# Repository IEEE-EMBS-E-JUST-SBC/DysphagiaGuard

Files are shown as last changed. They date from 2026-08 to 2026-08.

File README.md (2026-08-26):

---
publishDate: 2026-08-25T00:00:00Z

title: DysphagiaGuard || IEEE EMBS E-JUST SBC

excerpt: A MYOSA-based TinyML wearable that continuously monitors swallowing kinematics and classifies each swallow as Normal, Delayed/Incomplete, or Aspiration Risk in real time — alerting the wearer locally and notifying caregivers via a companion Flutter app.

image: DysphagiaGuard/cover.jpg

tags:
  - MYOSA
  - TinyML
  - Wearable Health Tech
  - Flutter
  - Embedded Systems
  - Biomedical Engineering
---

> Continuous, at-home swallowing surveillance — built entirely on the MYOSA Mini platform, with real-time on-device inference and live caregiver alerts.

<p align="center">
  
  
  
  
  
  
</p>

---

## Acknowledgements

Built by **Abdelrahman Hamza, Mariam Ibrahim, and Omar Salama**, Department of Biomedical and Mechatronics Engineering, Egypt-Japan University of Science and Technology (E-JUST), for **IEEE MYOSA 6.0**.

Thanks to the IEEE EMBS E-JUST Student Branch Chapter and the MYOSA organizing team for the platform and the opportunity to build and demo this project.

Full source: [[github.com/IEEE-EMBS-E-JUST-SBC/IEEE-MYOSA-6.0-DysphagiaGuard](https://github.com/IEEE-EMBS-E-JUST-SBC/DysphagiaGuard/)]

---

## Overview

Dysphagia (impaired swallowing) affects roughly **8% of the global population** and **more than half of stroke survivors**, along with a large share of patients with Parkinson's disease and ALS. The real danger isn't the swallowing difficulty itself — it's **aspiration**: food, liquid, or saliva entering the airway when a swallow fails to clear it properly. Silent aspiration in particular often goes unnoticed until it has already caused **aspiration pneumonia**, a leading cause of hospitalization and death in these patient groups.

Today, catching this requires a hospital visit — a Videofluoroscopic Swallow Study (VFSS) or a Fiberoptic Endoscopic Evaluation of Swallowing (FEES) — both episodic, expensive, and impossible to run continuously at home.

**DysphagiaGuard** closes that gap. It's a neck-worn wearable built entirely on the **MYOSA Mini platform** that captures laryngeal motion during swallowing via a 6-axis IMU, streams that data live, classifies each swallow event in real time, and pushes results to a **companion Flutter app** that a caregiver can check at a glance.

**Who it's for:** elderly individuals, stroke survivors, and patients with Parkinson's disease or ALS — populations where undetected aspiration carries serious, often silent, health risk.

### At a Glance

| | |
|---|---|
| **Platform** | MYOSA Mini (motherboard + IMU board + OLED + buzzer) |
| **Sampling rate** | ~100 Hz, 6-axis (3× accel + 3× gyro) |
| **Inference window** | 3 seconds (300 samples) → 48 engineered features |
| **Classes** | Normal · Delayed/Incomplete · Aspiration Risk |
| **Classification** | On-device TinyML (TFLite) + interpretable rule-based heuristic |
| **Connectivity** | WiFi → Firebase Realtime Database → Flutter app (BLE relay for extended range) |
| **Enclosure** | Laser-cut wood/acrylic, ~8.5 × 5 × 5 cm, neck-worn |
| **Alerting** | OLED status + buzzer (device) · push-style live dashboard (app) |

**Key features:**
* Continuous, non-invasive, neck-worn IMU monitoring of swallow kinematics — no hospital equipment required
* On-device / near-real-time classification into **Normal**, **Delayed/Incomplete**, or **Aspiration Risk**
* Local alerting via OLED status display and buzzer (silent for Normal, active alert pattern otherwise)
* Live companion **Flutter dashboard** with a real-time waveform, buffering indicator, event history log, and confidence scores
* Firebase Realtime Database as the live data bridge between the wearable and the mobile app
* On-device TinyML pipeline (TFLite, 48 hand-engineered time/frequency-domain features per 3-second window) alongside a rule-based heuristic classifier for interpretable, inspectable decision-making
* Custom laser-cut wood/acrylic and 3D-printed neck-mount enclosure for consistent, comfortable, repeatable sensor placement

### System Architecture

```mermaid
flowchart TB
    subgraph Wearable["Neck-Worn Wearable"]
        IMU["MYOSA IMU Board<br/>6-axis Accel + Gyro"]
        MB["MYOSA Motherboard<br/>ESP32 · WiFi · BLE"]
        OLED["OLED Display"]
        BUZ["Buzzer"]
        IMU -->|I2C| MB
        MB -->|status| OLED
        MB -->|alert pattern| BUZ
    end

    subgraph Cloud["Firebase Realtime Database"]
        LIVE["/devices/deviceId/live<br/>raw IMU stream ~100Hz"]
        STATUS["/devices/deviceId/status<br/>classification result"]
    end

    subgraph App["Flutter Companion App"]
        FEED["Live IMU Feed Listener"]
        FEAT["Feature Extractor<br/>48 features / 3s window"]
        CLS["Classifier<br/>TFLite + Heuristic"]
        UI["Dashboard UI<br/>waveform · history · alerts"]
        FEED --> FEAT --> CLS --> UI
        CLS -->|writes result| STATUS
    end

    MB -->|WiFi write ~100Hz| LIVE
    LIVE -->|stream| FEED
    STATUS -->|poll 500ms| MB

    style Wearable fill:#1b2444,stroke:#8b5cf6,color:#fff
    style Cloud fill:#2b2408,stroke:#facc15,color:#fff
    style App fill:#0a2a2a,stroke:#22d3ee,color:#fff
```

### Signal Processing & Classification Pipeline

```mermaid
flowchart LR
    A["Raw IMU Sample<br/>ax, ay, az, gx, gy, gz"] --> B["Buffer 3s Window<br/>300 samples @ 100Hz"]
    B --> C["Feature Extraction<br/>8 features × 6 axes = 48"]
    C --> D["Normalize<br/>(x − mean) / scale"]
    D --> E{"Classifier"}
    E -->|TFLite path| F["Quantized NN<br/>softmax [3 classes]"]
    E -->|Heuristic path| G["Gyro/Az Motion Rules<br/>peak · duration · settle · cough-spike"]
    F --> H["Result"]
    G --> H["Result"]
    H --> I{"Class?"}
    I -->|Normal| J["OLED: Normal<br/>Buzzer: silent"]
    I -->|Delayed/Incomplete| K["OLED: Delayed<br/>Buzzer: 1s on/off"]
    I -->|Aspiration Risk| L["OLED: Aspiration Risk<br/>Buzzer: 1s on/off"]
    H --> M["Firebase /status<br/>+ Event History Log"]

    style E fill:#8b5cf6,color:#fff
    style I fill:#22d3ee,color:#000
```

<details>
<summary><b>▶ Click to expand: per-window feature list (48 features)</b></summary>

For each of the 6 IMU channels (`ax, ay, az, gx, gy, gz`), 8 features are computed per 3-second window:

| # | Feature | What it captures |
|---|---|---|
| 1 | Mean | DC offset / resting bias |
| 2 | Standard deviation | Overall variability |
| 3 | RMS | Signal magnitude |
| 4 | Peak (max abs) | Sharpest motion moment |
| 5 | Energy | Total motion intensity |
| 6 | Zero-crossing rate | Oscillation frequency |
| 7 | Spectral centroid | "Center of mass" of frequency content |
| 8 | Spectral flatness | Tonal vs. noise-like character |

`6 channels × 8 features = 48` — normalized with `StandardScaler` stats exported alongside the trained model.

</details>

---

## Demo / Examples

### Images
<p align="center">
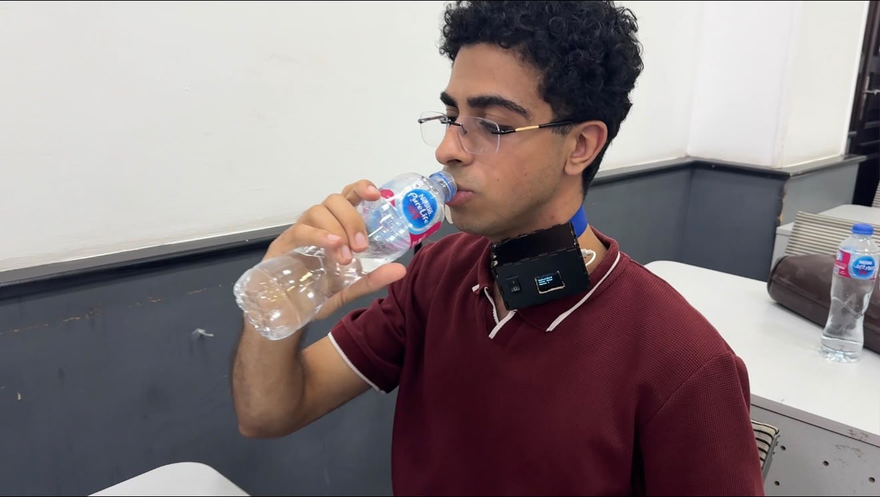
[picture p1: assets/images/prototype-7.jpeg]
  <br/>
  <i>Volunteer wearing DysphagiaGuard on the neck strap during a live testing session</i>
</p>

<p align="center">
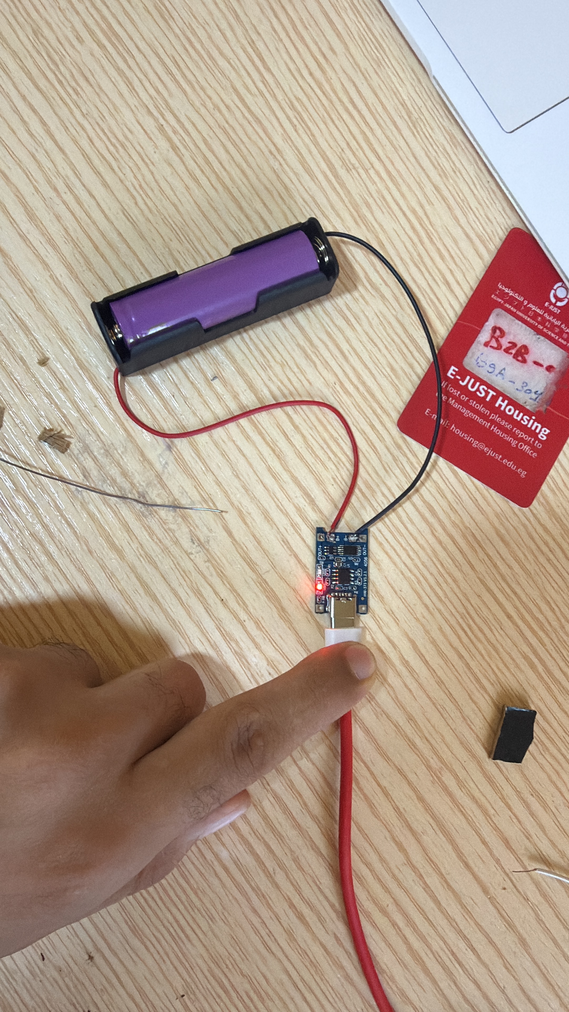
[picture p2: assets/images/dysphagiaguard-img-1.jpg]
  <br/>
  <i>Bench build: MYOSA OLED display board and audio/sensor daughterboard wired and test-fitted inside the laser-cut enclosure before final assembly</i>
</p>

<p align="center">
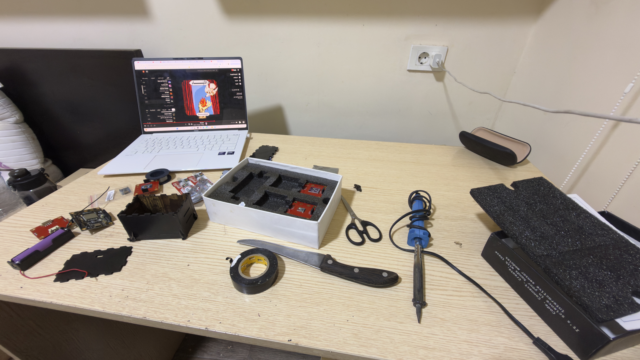
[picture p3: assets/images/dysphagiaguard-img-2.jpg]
  <br/>
  <i>Fitting the OLED module and Li-ion cell into the enclosure — checking clearance and wire routing before gluing panels shut</i>
</p>

<p align="center">
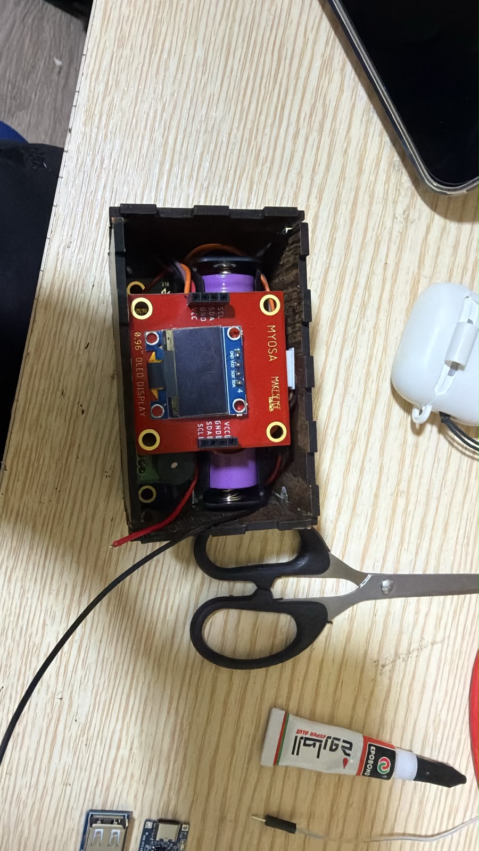
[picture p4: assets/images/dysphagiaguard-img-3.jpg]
  <br/>
  <i>Full electronics stack laid out and wired on the bench: battery, charging/boost module, MYOSA motherboard, IMU board, and OLED display, prior to enclosure integration</i>
</p>

<p align="center">
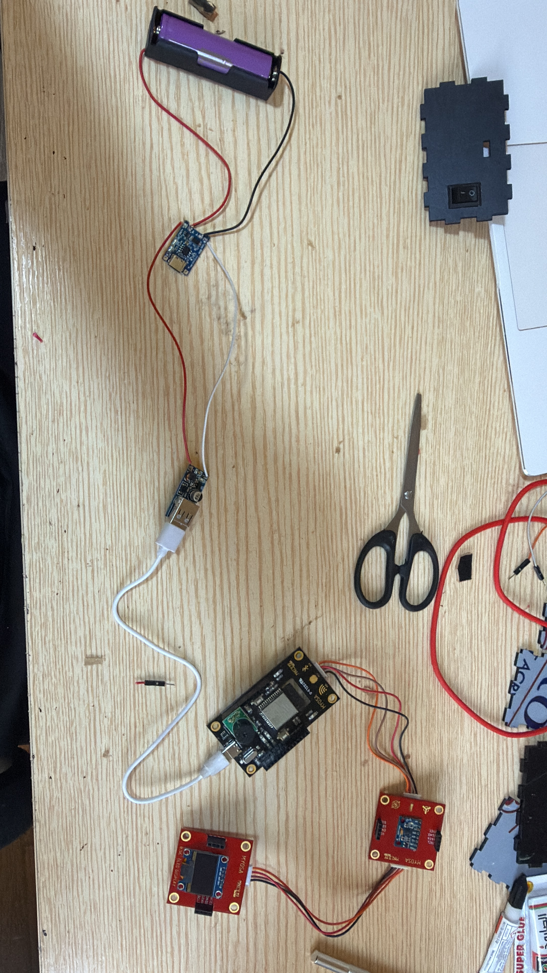
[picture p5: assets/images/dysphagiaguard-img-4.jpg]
  <br/>
  <i>Close-up of the MYOSA motherboard (MCU, BLE, WiFi, buzzer) connected to the IMU sensor board, mid-assembly inside the enclosure shell</i>
</p>

<p align="center">
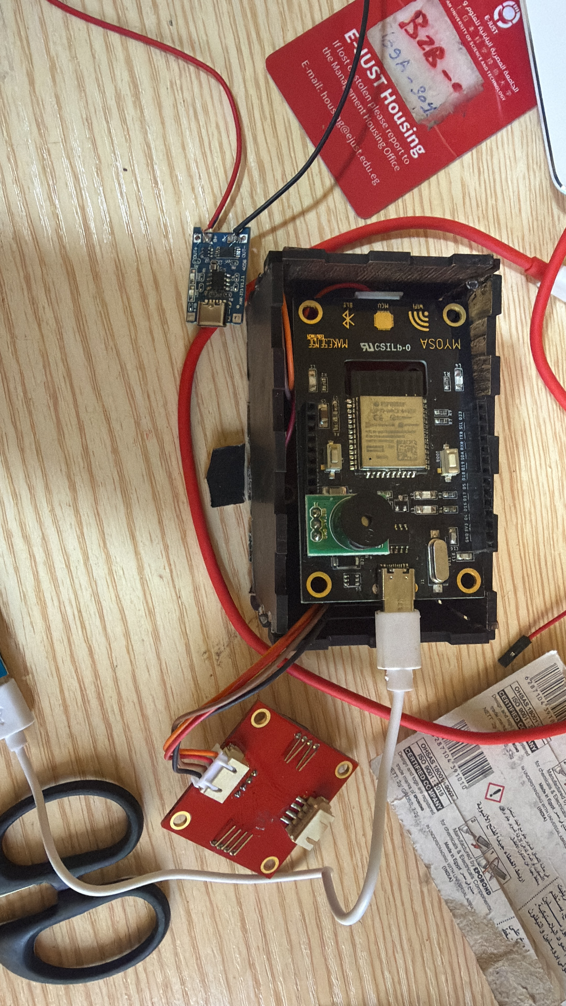
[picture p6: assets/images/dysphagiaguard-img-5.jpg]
  <br/>
  <i>Full kit unboxing and workstation setup: MYOSA sensor boards, laser-cut enclosure panels, battery, adhesives, and tools laid out before assembly</i>
</p>

<p align="center">
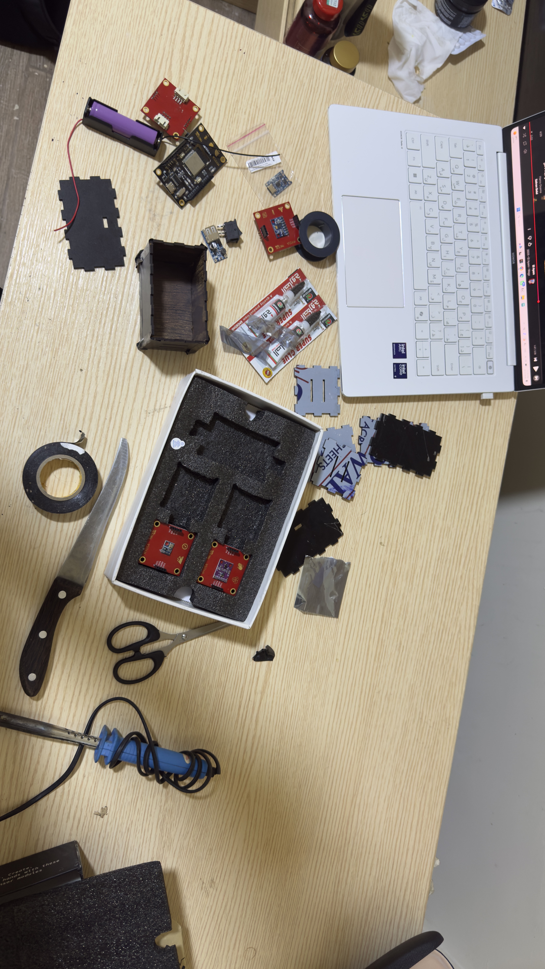
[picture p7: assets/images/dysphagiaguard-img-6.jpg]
  <br/>
  <i>Assembly desk: enclosure panels, MYOSA boards, and soldering iron set up for the build session</i>
</p>

<p align="center">
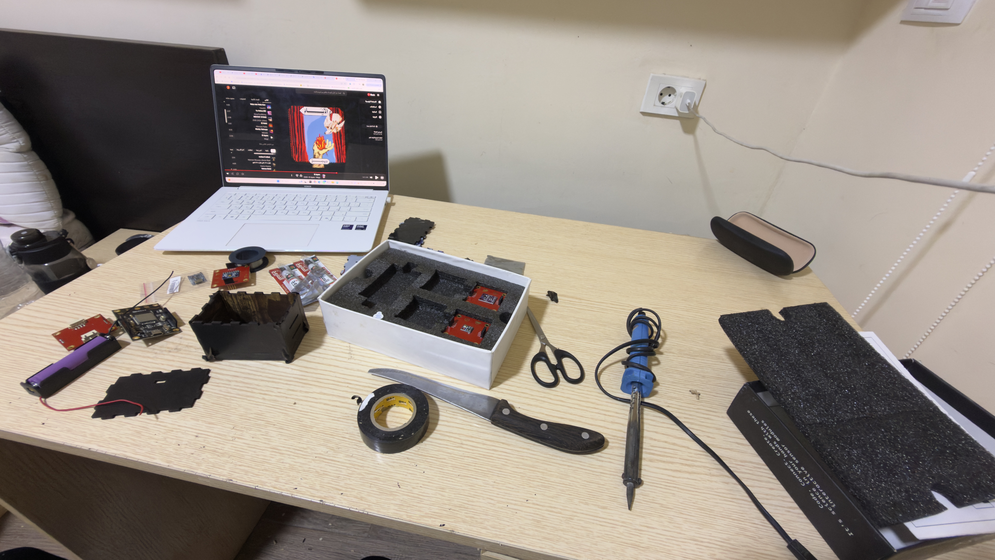
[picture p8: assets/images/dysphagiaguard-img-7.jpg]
  <br/>
  <i>Firmware development in progress — flashing and debugging the Arduino sketch on the MYOSA dev module while assembling the enclosure alongside it</i>
</p>

<p align="center">
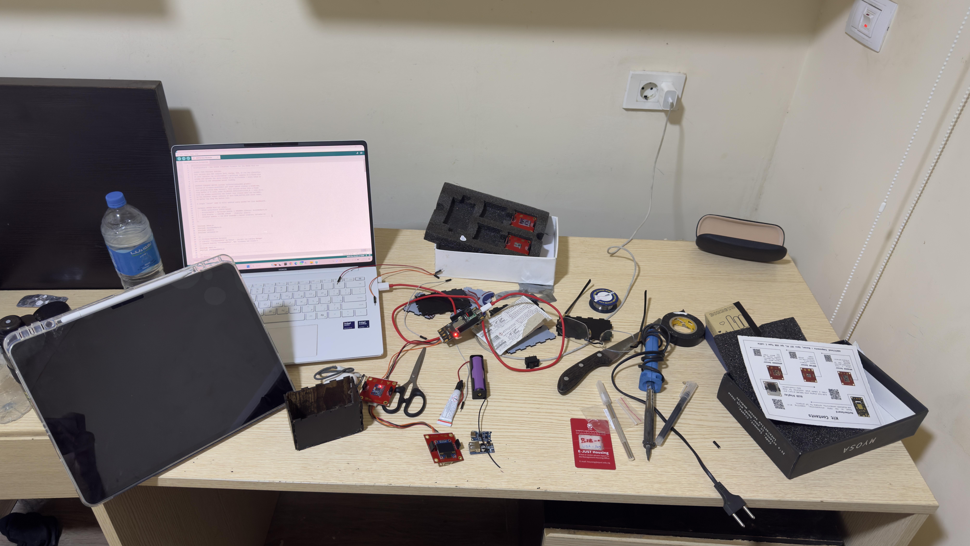
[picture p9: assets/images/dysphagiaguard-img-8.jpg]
  <br/>
  <i>Debugging session: MYOSA board powered on (status LED lit) and connected via USB while the firmware is edited and re-flashed</i>
</p>

<p align="center">
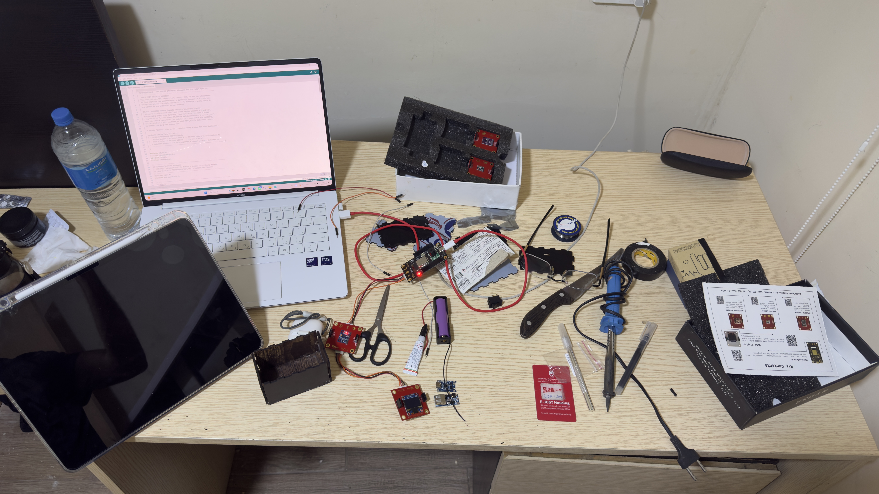
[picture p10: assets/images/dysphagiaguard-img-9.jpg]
  <br/>
  <i>Continued firmware debugging and wiring checks at the desk, cross-referencing the Arduino IDE serial output against the physical connections</i>
</p>

<p align="center">
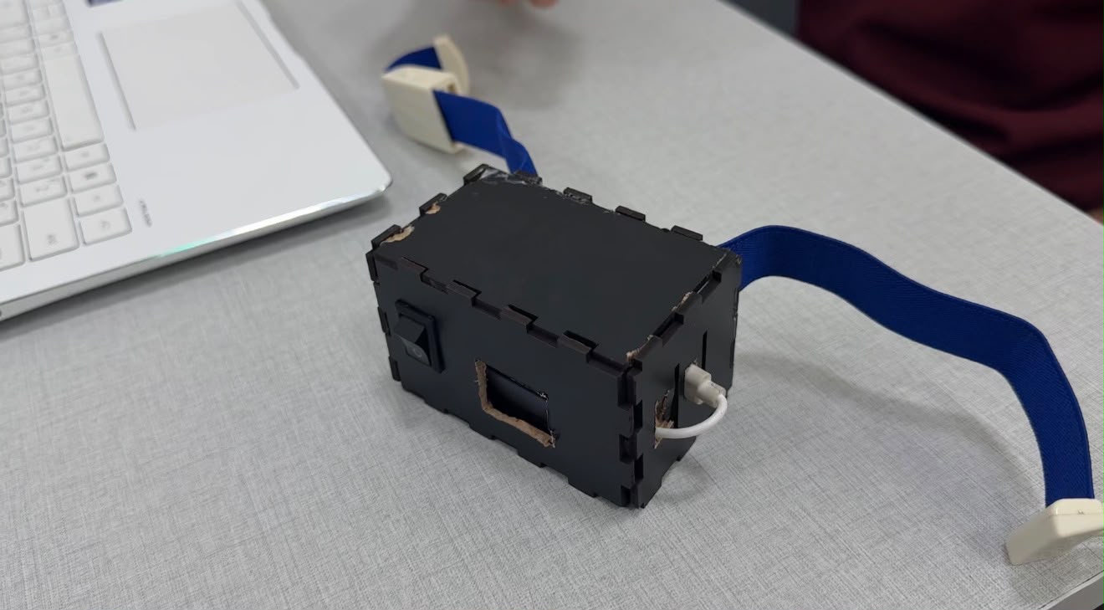
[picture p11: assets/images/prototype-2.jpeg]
  <br/>
  <i>Final wiring pass before closing up the enclosure — components laid out for one last continuity check</i>
</p>

<p align="center">
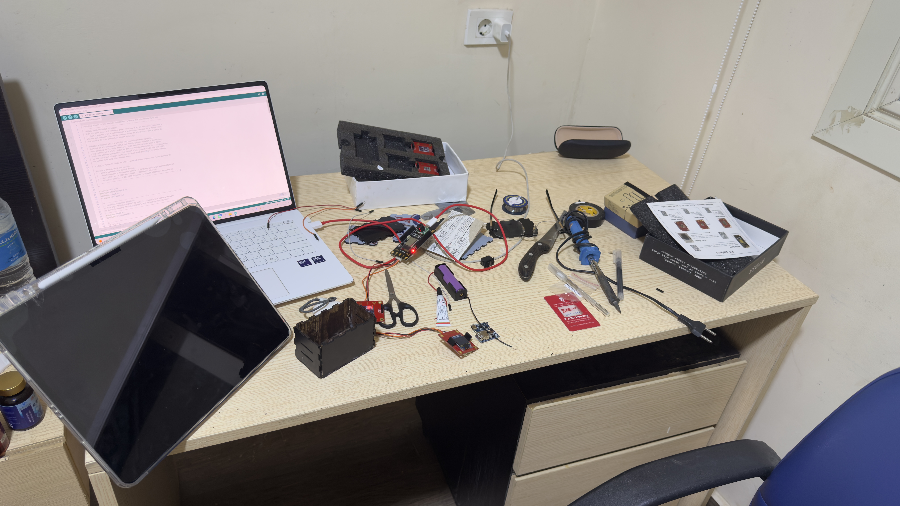
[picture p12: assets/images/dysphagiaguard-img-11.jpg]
  <br/>
  <i>Enclosure lid removed, showing the OLED display, IMU board, and battery seated inside the finished laser-cut wood housing</i>
</p>

<p align="center">
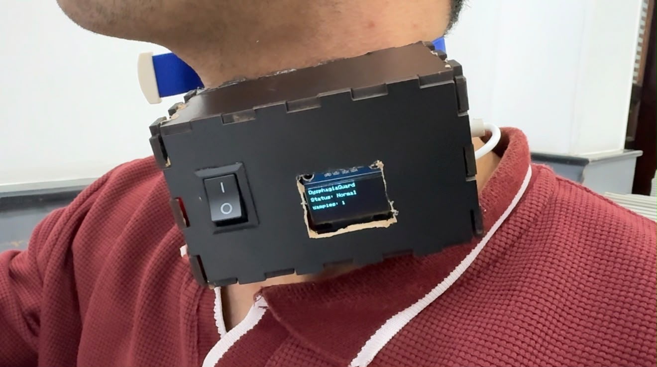
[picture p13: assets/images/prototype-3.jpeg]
  <br/>
  <i>Assembled wearable worn on a volunteer's neck, OLED showing a live "Status: Normal" reading during a test session</i>
</p>

### Videos

**🎥 Project Presentation & Testing**

<video controls width="100%">
  <source src="/dysphagiaguard-presentation-and-testing.mp4" type="video/mp4">
</video>

**🎥 Backstage / Build Process**

<video controls width="100%">
  <source src="/dysphagiaguard-backstage.mp4" type="video/mp4">
</video>

> ⚠️ **Note:** If the video not loading on github, please try to download it locally to play in normal way.

--

## Features (Detailed)

### 1. Continuous IMU Sensing of Swallow Kinematics

The MYOSA IMU sensor board is worn over the laryngeal prominence and streams raw 6-axis data (3-axis acceleration + 3-axis angular velocity) at **~100 Hz**. This captures the characteristic vertical displacement of the hyoid-laryngeal complex during a swallow — the primary kinematic signature the whole pipeline is built around.

Each sample is pushed live to Firebase in the shape:

```json
{
  "ax": 0.01, "ay": -0.02, "az": 0.98,
  "gx": 0.4,  "gy": -0.1,  "gz": 0.05,
  "t":  1234567
}
```

```mermaid
sequenceDiagram
    participant Firmware as ESP32 Firmware
    participant RTDB as Firebase RTDB
    participant App as Flutter App

    loop every ~10ms
        Firmware->>Firmware: read IMU (ax,ay,az,gx,gy,gz)
        Firmware->>RTDB: write /devices/id/live
    end
    RTDB-->>App: onValue stream
    App->>App: buffer into 300-sample window
```

### 2. On-Device Signal Processing & Feature Extraction

Every 3-second window (300 samples at 100 Hz) is reduced to **48 features** — 8 features per axis (mean, std, RMS, peak, energy, zero-crossing rate, spectral centroid, spectral flatness) across all 6 IMU channels, in a fixed order that must exactly match the order used during model training. These are then normalized with the same scaler statistics exported from the training pipeline before being fed to the classifier.

### 3. Dual Classification Approach: TinyML Model + Interpretable Heuristic

Two classification paths are implemented side by side:

- **TinyML path (TFLite):** A quantized neural network trained in Edge Impulse takes the 48 normalized features and outputs softmax probabilities across `[normal, delayed_incomplete, aspiration_risk]`.
- **Heuristic path:** A transparent, rule-based classifier that reasons directly over calibrated gyroscope-magnitude and accelerometer-Z motion signatures — peak magnitude, event duration, settle time, and secondary "cough-like" spikes — against a per-device baseline captured during a 30-second calibration hold. This keeps the decision logic inspectable rather than a black box, and was used to drive the live demo classification while the TFLite path stays wired up for its intended on-device role.

```mermaid
flowchart TD
    S["30s Calibration Hold<br/>device at rest"] --> B["Baseline: gyro/az bias<br/>+ noise floor"]
    B --> W["New 3s Window"]
    W --> P{"Peak gyro mag<br/>> threshold?<br/>AND az excursion signature?"}
    P -->|No| U["Unknown / No Event"]
    P -->|Yes| SEC{"Secondary spike<br/>OR sharp peak +<br/>slow settle?"}
    SEC -->|Yes| ASP["Aspiration Risk"]
    SEC -->|No| SLOW{"Slow settle OR<br/>long duration OR<br/>slow time-to-peak?"}
    SLOW -->|Yes| DEL["Delayed / Incomplete"]
    SLOW -->|No| NORM["Normal Swallow"]
```

### 4. Local Alerting (OLED + Buzzer)

The MYOSA OLED display shows the live classification status and running sample count. The buzzer stays **silent for Normal Swallow** and rings in a 1-second on/off pattern for **Delayed** or **Aspiration Risk** classifications, giving the wearer an immediate, unambiguous physical alert without needing to look at a screen.

| Classification | OLED | Buzzer |
|---|---|---|
| Normal Swallow | `Status: Normal` | Silent |
| Delayed / Incomplete | `Status: Delayed` | 1s on / 1s off |
| Aspiration Risk | `Status: Aspiration` | 1s on / 1s off |

### 5. Firebase Realtime Database as the Live Bridge

Firebase RTDB is the single source of truth connecting the firmware and the mobile app:

- `/devices/<deviceId>/live` — firmware writes each raw IMU sample here (~100 Hz)
- `/devices/<deviceId>/status` — classification result written back, polled by the firmware every 500 ms to drive the buzzer/OLED

The Flutter app listens to `/live` for real-time streaming and visualization, and writes classification results back to `/status`.

### 6. Flutter Companion Dashboard

The companion app (built with Flutter + `firebase_database` + `flutter_litert` for on-device TFLite inference) gives the caregiver a live, readable view of:

- A **scrolling waveform** of the incoming IMU signal, with a glowing "live" leading edge
- A **buffering ring** showing progress toward the next 3-second inference window
- **Metric cards** for current classification, confidence, and session stats
- A **scrollable event history** log with color-coded risk levels (mint = normal, amber = delayed, coral = aspiration risk) and timestamps
- A **calibration flow** — a 30-second still-hold at the start of each session to capture the per-wearer motion baseline used by the heuristic classifier

<details>
<summary><b>▶ Click to expand: Flutter app module map</b></summary>

```mermaid
flowchart TB
    main["main.dart"] --> dash["DashboardScreen"]
    dash --> wave["LiveWaveform"]
    dash --> ring["BufferRing"]
    dash --> metrics["MetricCard / EventHistoryTile"]
    dash --> feed["LiveImuFeed"]
    feed --> imu["ImuSample model"]
    feed --> heur["HeuristicSwallowClassifier"]
    feed --> tfl["SwallowClassifier (TFLite)"]
    tfl --> fe["FeatureExtractor"]
    fe --> fft["SimpleFFT"]
    tfl --> fs["FeatureStats (scaler + config)"]
```

</details>

### 7. Custom Wearable Enclosure

A lightweight, laser-cut and 3D-printed neck-mount enclosure (approx. **8.5 × 5 × 5 cm**) houses the MYOSA motherboard and IMU board in a fixed anatomical position, minimizing motion artifact from enclosure shifting and keeping sensor placement repeatable across wear sessions. Panels were laser-cut from **wood and acrylic** from a DXF layout, then assembled around the MYOSA stack for a low-mass, breathable, all-day-wearable housing.

---

## Usage Instructions

### 1. Flash the Firmware

Open `DysphagiaGuard_Final_Code.ino` in the Arduino IDE with the MYOSA/ESP32 board package installed, then set your own WiFi and Firebase credentials before flashing:

```cpp
#define WIFI_SSID          "YOUR_WIFI_SSID"
#define WIFI_PASSWORD      "YOUR_WIFI_PASSWORD"
#define FIREBASE_HOST      "https://YOUR_PROJECT-default-rtdb.firebaseio.com/"
#define FIREBASE_AUTH_TOKEN "YOUR_FIREBASE_DATABASE_SECRET"
#define DEVICE_ID          "dysphagiaguard-01"
```

> ⚠️ **Security note:** never commit real WiFi passwords or Firebase database secrets to a public repository or blog submission. Treat the database secret as a password — generate it from **Firebase Console → Project Settings → Service Accounts / Database Secrets**, and rotate it immediately if it's ever been shared or committed in plaintext.

The firmware includes a `LOCAL_STATUS_TEST_MODE` flag that bypasses WiFi/Firebase entirely and cycles through `Normal → Aspiration → Delayed` locally every 5 seconds — useful for verifying the buzzer and OLED in isolation before testing the full network pipeline.

### 2. Set Up the Flutter App

```bash
flutter pub get
flutterfire configure   # generates YOUR real firebase_options.dart — do not reuse the sample one
flutter run
```

Make sure the `deviceId` in `main.dart` matches the `DEVICE_ID` set in the firmware:

```dart
home: const DashboardScreen(deviceId: 'dysphagiaguard-01'),
```

Confirm the TFLite model and stats files are bundled as assets in `pubspec.yaml`:

```yaml
flutter:
  assets:
    - assets/models/dysphagia_imu_model_float32.tflite
    - assets/models/feature_stats.json
```

### 3. Calibrate Before Each Session

On launch, hold the wearable still for the 30-second calibration window. This captures the gyroscope/accelerometer resting baseline the heuristic classifier uses to detect motion events against.

### 4. Laser-Cut the Enclosure

Use `esp32_enclosure_8_5x5x5cm.dxf` with your laser cutter's software (e.g. LightBurn) on 3 mm wood or acrylic sheet. Panels are sized to house the MYOSA motherboard and IMU board in a fixed neck-mount orientation.

<details>
<summary><b>▶ Click to expand: full setup checklist</b></summary>

- [ ] Rotate/replace the Firebase database secret before flashing (never reuse the one from this repo)
- [ ] Flash `DysphagiaGuard_Final_Code.ino` with your own WiFi + Firebase credentials
- [ ] Confirm `DEVICE_ID` in firmware matches `deviceId` in `main.dart`
- [ ] Run `flutterfire configure` to generate your own `firebase_options.dart`
- [ ] Bundle `dysphagia_imu_model_float32.tflite` + `feature_stats.json` as Flutter assets
- [ ] Laser-cut enclosure panels from `esp32_enclosure_8_5x5x5cm.dxf`
- [ ] Assemble electronics into enclosure, checking wire routing before gluing
- [ ] Power on, complete the 30s calibration hold, verify OLED shows `Status: Normal`

</details>

---

## Tech Stack

* **MYOSA Mini Platform** — motherboard, IMU sensor board, OLED display, buzzer, BLE
* **C++ / Arduino Framework** — ESP32 firmware (`AccelAndGyro`, `oled`, `FirebaseESP32`, `WiFi`)
* **Firebase Realtime Database** — live IMU streaming + classification status bridge
* **Flutter / Dart** — cross-platform companion mobile app
* **TensorFlow Lite (`flutter_litert`)** — on-device TinyML inference
* **Edge Impulse** — TinyML model training and quantization workflow
* **Python / NumPy / scikit-learn** (training pipeline) — feature engineering and `StandardScaler` normalization
* **Laser cutting (wood & acrylic)** + **3D printing** — custom neck-mount wearable enclosure

---

## Requirements / Installation

**Firmware (Arduino IDE):**

```plaintext
Board: MYOSA / ESP32
Libraries: Wire, AccelAndGyro, oled, WiFi, FirebaseESP32
```

**Flutter app:**

```bash
flutter pub get
```

Key packages used: `firebase_core`, `firebase_database`, `flutter_litert`, `intl`.

---

## File Structure (Optional)

```
/DysphagiaGuard
  ├─ dysphagiaguard.md
  ├─ cover.jpg
  ├─ (project images...)
  ├─ dysphagiaguard-presentation-and-testing.mp4
  ├─ dysphagiaguard-backstage.mp4
  │
  ├─ firmware/
  │   └─ DysphagiaGuard_Final_Code.ino
  │
  ├─ ml_model/
  │   ├─ dysphagia_imu_model_float32.tflite
  │   └─ feature_stats.json
  │
  ├─ flutter_app/
  │   ├─ main.dart
  │   ├─ firebase_options.dart          # regenerate with your own `flutterfire configure`
  │   ├─ screens/
  │   │   └─ dashboard_screen.dart
  │   ├─ widgets/
  │   │   ├─ buffer_ring.dart
  │   │   ├─ live_waveform.dart
  │   │   ├─ metric_widgets.dart
  │   │   └─ alert_banner.dart
  │   ├─ inference/
  │   │   ├─ feature_extractor.dart
  │   │   ├─ feature_stats.dart
  │   │   ├─ simple_fft.dart
  │   │   ├─ swallow_classifier.dart
  │   │   └─ heuristic_swallow_classifier.dart
  │   ├─ data/
  │   │   ├─ live_imu_feed.dart
  │   │   └─ imu_sample.dart
  │   └─ theme/
  │       └─ app_theme.dart
  │
  └─ hardware/
      └─ esp32_enclosure_8_5x5x5cm.dxf
```

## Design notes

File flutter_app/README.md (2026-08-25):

# DysphagiaGuard — Flutter Companion App

On-device swallow & aspiration-risk monitor. Reads raw 6-axis IMU samples
pushed to Firebase by the ESP32/MYOSA wearable, buffers 3-second windows,
extracts features, and runs a TinyML (TFLite) classifier **directly on
the phone** — no cloud inference.

## What changed from the template

This was adapted from a physiological/environmental monitoring template
(reading a `score`/`rp`/`re` composite). Everything has been re-pointed at
DysphagiaGuard's actual pipeline:   

| Area | Was | Now |
|---|---|---|
| Firebase path | `/devices/<id>/live` → `{score, level, rp, re, tempC, updatedAtMs}` | `/devices/<id>/live` → `{ax, ay, az, gx, gy, gz, t}` (raw IMU, one write per sample) |
| Classification | Threshold on composite score | TFLite model output (normal / delayed-incomplete / aspiration-risk) |
| Firebase project | Real project `bioflex-237aa` (had live API keys) | Placeholder `dysphagiaguard` project — **you must run `flutterfire configure`** |
| UI | Score gauge + Rp/Re cards | Live IMU waveform, buffer-fill ring, 3-class probability bars, event history log |

**Security note:** the original `firebase_options.dart` you uploaded contained
real, live API keys for an existing Firebase project. Those have been
stripped and replaced with placeholders — do not reuse a stranger's
production keys in a renamed app. Run `flutterfire configure` against
your own project.

## Setup

```bash
flutter pub get

# Generates real Firebase credentials for YOUR project,
# overwrites lib/firebase_options.dart
flutterfire configure

# Point the app at your device's Firebase key — edit lib/main.dart:
#   home: const DashboardScreen(deviceId: 'your-device-id')

flutter run
```

The app expects these two files (already included) as bundled assets:
- `assets/models/dysphagia_imu_model_float32.tflite`
- `assets/models/feature_stats.json`

These come straight from the Colab training notebook's export step. If
you retrain the model, re-copy both files here — they must match
exactly (feature order + normalization stats are baked into
`feature_stats.json`, and the app trusts it completely).

## Firmware contract

The ESP32/MYOSA firmware should write to `/devices/<deviceId>/live` once
per IMU sample (~100 Hz to match `feature_stats.json`'s
`sampling_rate_hz`):

```json
{
  "ax": 0.01, "ay": -0.02, "az": 0.98,
  "gx": 0.4,  "gy": -0.1,  "gz": 0.05,
  "t": 1234567
}
```

`t` is the device's `millis()` — used only to detect duplicate/stale
writes, not for wall-clock display. The app buffers 300 consecutive
samples (3 seconds at 100 Hz) into one window, runs one classification
per window, then starts a fresh buffer — non-overlapping windows, matching
how the training data was constructed.

`database.rules.json` has been updated to validate this new shape
(`ax, ay, az, gx, gy, gz, t` instead of `score, level, rp, re, tempC,
updatedAtMs`). Deploy it with:

```bash
firebase deploy --only database
```

## On-device inference pipeline (how it actually works)

1. `LiveImuFeed` listens to the Firebase path and buffers incoming samples.
2. Every 300 samples, `FeatureExtractor` computes 8 features per axis
   (mean, std, RMS, peak, energy, zero-crossing rate, spectral centroid,
   spectral flatness) — 48 features total, in the exact order the model
   was trained on.
3. `SimpleFFT` computes spectral centroid/flatness using a **direct DFT**
   (not a padded FFT) — this was deliberately chosen because the training
   pipeline (numpy `rfft`) operates on the raw 300-sample window without
   zero-padding. An earlier padded-FFT approach was verified against
   numpy and, while mathematically correct as an FFT, produced ~10%
   drift in spectral features vs. training due to the padding changing
   bin spacing. The direct DFT matches numpy to floating-point precision.
   At 300 samples computed once per 3-second window, the O(N²) cost is
   trivial on a phone.
4. `FeatureStats.normalize()` applies the same `(x - mean) / scale` used
   by scikit-learn's `StandardScaler` during training.
5. `SwallowClassifier` runs the TFLite interpreter and returns softmax
   probabilities for the 3 classes.

## Known limitations / next steps

- **Model is trained on synthetic data.** See the Colab notebook — retrain
  on real labeled recordings before relying on this for actual patient
  monitoring. The pipeline (feature extraction, normalization, model
  architecture) stays the same; only the training data needs to change.
- **Non-overlapping windows** means there's up to a 3-second delay between
  a swallow event and its classification appearing. If you need faster
  response, consider overlapping windows (e.g. classify every 1s using
  the trailing 3s of samples) — this requires re-wiring `LiveImuFeed`'s
  buffering logic to a sliding window instead of take-and-clear.
- **No authentication** — `database.rules.json` still allows open
  read/write. Fine for a prototype, not for a shipped product handling
  health data.

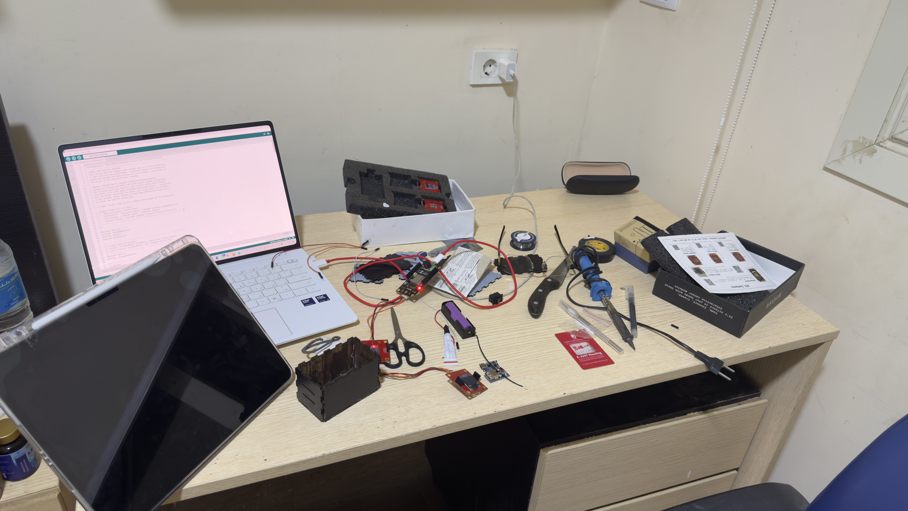
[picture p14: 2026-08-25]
assets/images/dysphagiaguard-img-10.jpg

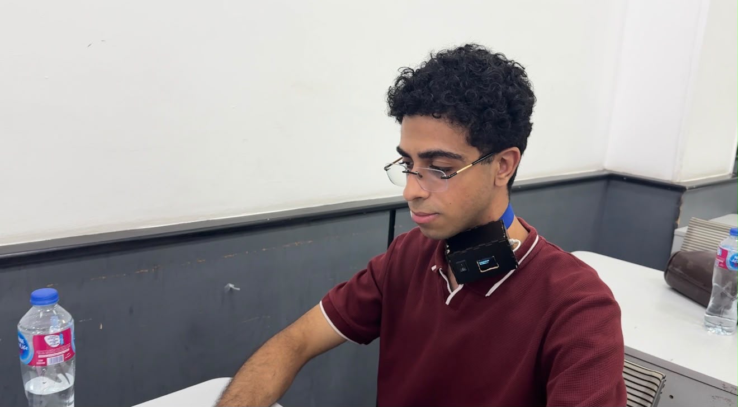
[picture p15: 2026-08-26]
assets/images/prototype-1.jpeg

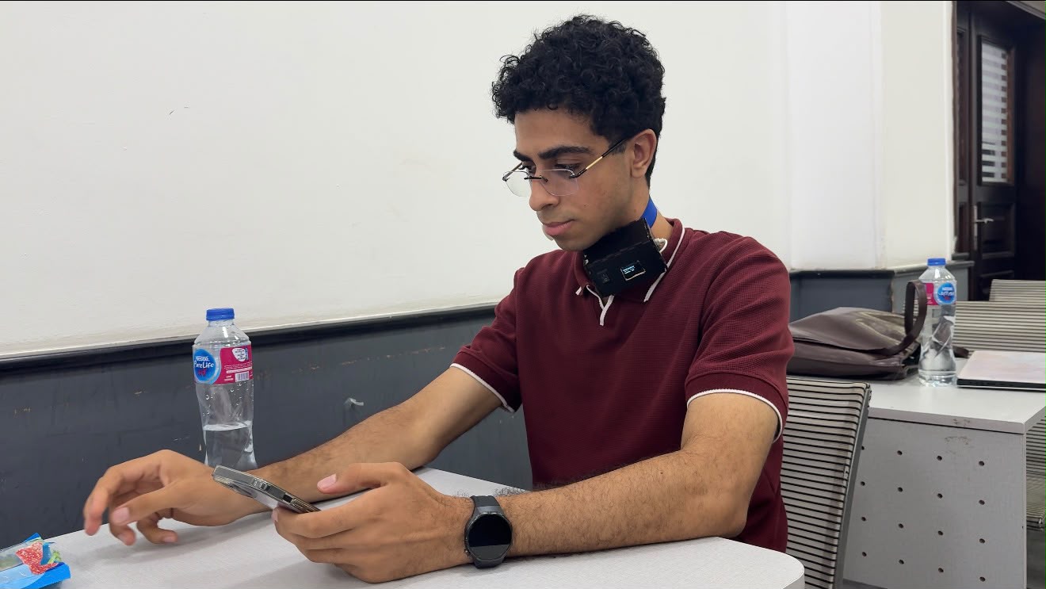
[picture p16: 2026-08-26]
assets/images/prototype-5.jpeg

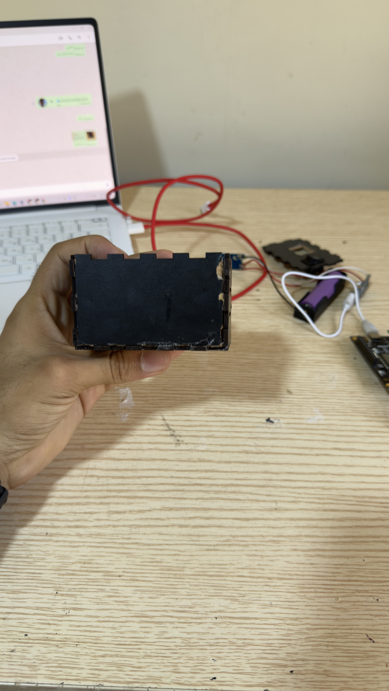
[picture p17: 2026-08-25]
assets/images/dysphagiaguard-img-15.jpg

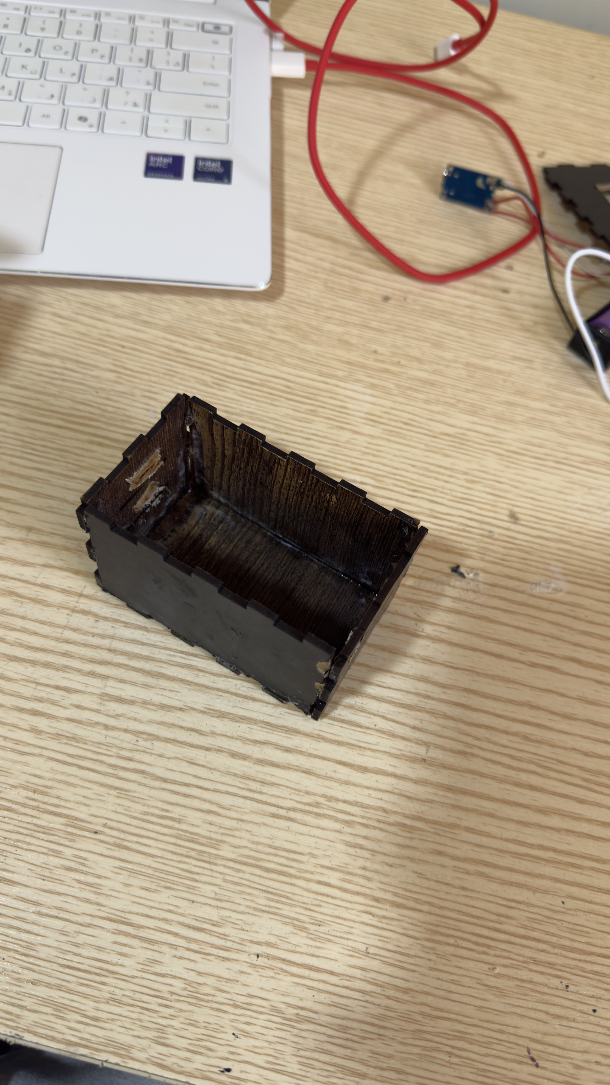
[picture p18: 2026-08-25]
assets/images/dysphagiaguard-img-18.jpg

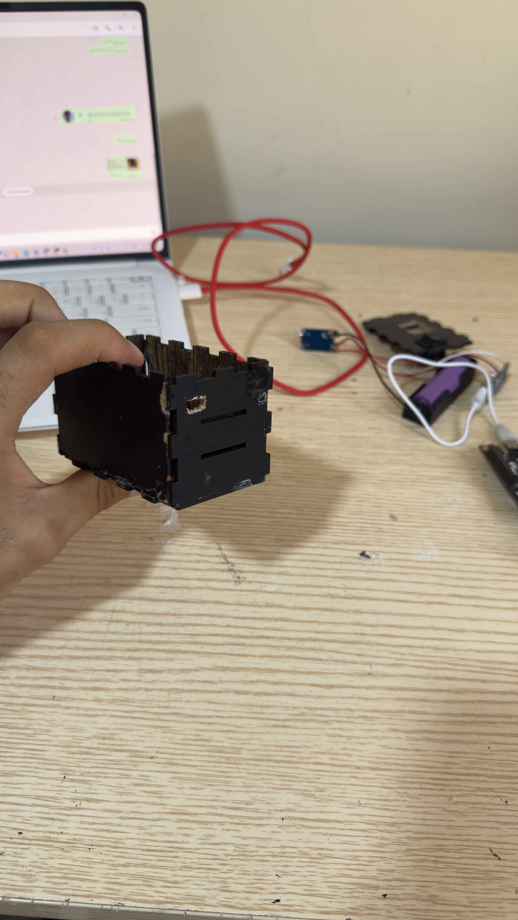
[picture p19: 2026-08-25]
assets/images/dysphagiaguard-img-17.jpg

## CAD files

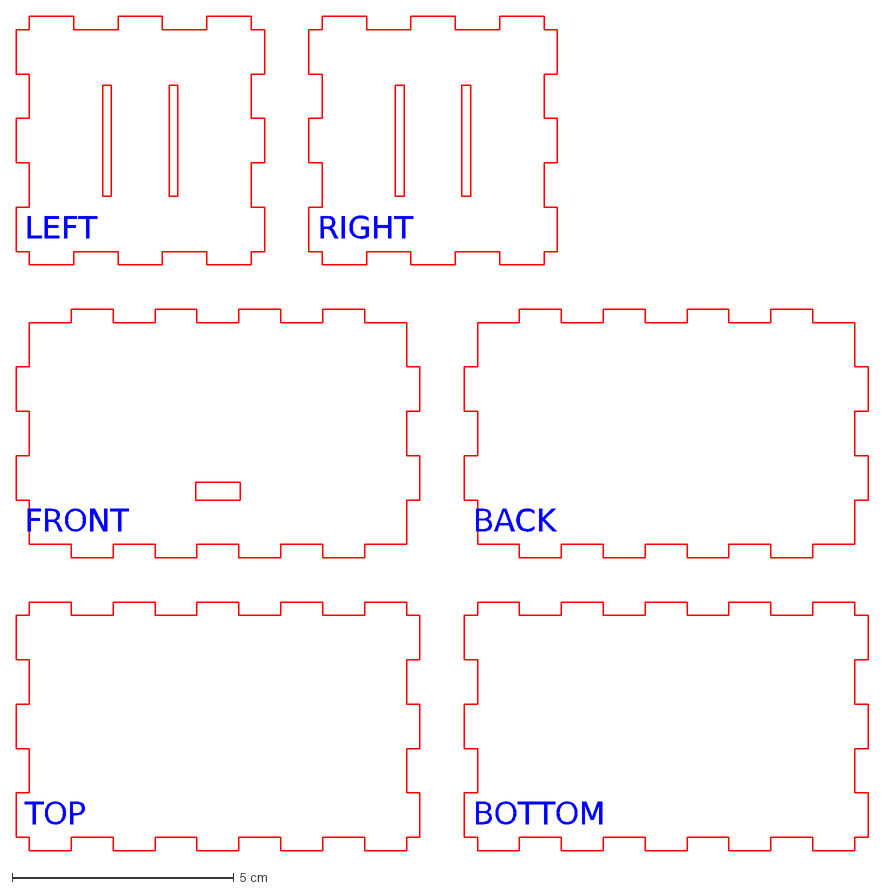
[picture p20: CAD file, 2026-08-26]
hardware/esp32_enclosure_8.5x5x5cm.dxf
TOP
BOTTOM
FRONT
BACK
LEFT
RIGHT

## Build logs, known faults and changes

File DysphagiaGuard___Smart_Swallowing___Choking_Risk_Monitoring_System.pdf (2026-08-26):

# DysphagiaGuard: A MYOSA-Based TinyML Wearable System for Continuous Dysphagia Monitoring and Aspiration Risk Early Detection

Abdelrahman Hamza, Mariam Ibrahim, Omar Salama Department of Biomedical and Mechatronics Engineering Egypt Japan University of Science & Technology github.com/IEEE-EMBS-E-JUST-SBC/IEEE-MYOSA-6.0-DysphagiaGuard

Abstract

Dysphagia, or impaired swallowing function, affects approximately 8% of the global population and more than half of stroke survivors, as well as a substantial proportion of patients with neurological disorders such as Parkinson’s disease and amyotrophic lateral sclerosis (ALS). Undetected aspiration events arising from impaired swallowing coordination frequently progress to aspiration pneumonia, prolonged hospitalization, and, in severe cases, death. Despite this burden, no affordable, continuous, at-home monitoring solution currently exists; clinical assessment remains limited to episodic, resource-intensive procedures performed within hospital settings. This paper presents DysphagiaGuard, a non-invasive wearable monitoring system constructed entirely on the MYOSA Mini IoT platform. The system integrates a MYOSA inertial measurement unit (IMU) sensor board to capture laryngeal motion and swallowing kinematics, together with a MYOSA vibration sensor board to record mechanomyographic signals generated by the submental muscle group during deglutition. The MYOSA motherboard functions as the sole computational and coordination unit, performing sensor acquisition, signal preprocessing, and on-device inference using a TinyML classification model developed in Edge Impulse. The model classifies each swallowing event into one of three categories: normal swallow, delayed or incomplete swallow, and high-risk aspiration event. Classification outcomes are communicated to the wearer through the MYOSA OLED display and buzzer, and relayed to caregivers via Bluetooth Low Energy (BLE) through the MYOSA mobile application. Supporting hardware contributions include a lightweight 3D-printed neck-mounted sensor holder for consistent sensor placement and a BLE relay module for extended-range caregiver notification. By requiring no external microcontroller, custom PCB, or proprietary clinical equipment, DysphagiaGuard demonstrates a clinically meaningful, low-cost pathway toward continuous swallowing surveillance outside the hospital, with direct implications for early aspiration pneumonia prevention in elderly and neurologically impaired populations.

### 1 Introduction

### 1.1 Clinical Burden of Dysphagia

Dysphagia is a swallowing disorder characterized by impaired or uncoordinated transfer of food and liquid from the oral cavity to the esophagus. Epidemiological estimates indicate that dysphagia affects approximately 8% of the global population across all age groups [1], with substantially higher prevalence among specific clinical populations. More than 50% of stroke survivors experience some degree of post-stroke dysphagia during the acute recovery phase [2], and swallowing impairment is similarly prevalent among patients with Parkinson’s disease, where progressive bulbar dysfunction compromises airway protection during swallowing [3], and among ALS patients, for whom dysphagia is frequently an early and progressively worsening symptom of bulbar motor neuron degeneration [4].
The principal danger associated with dysphagia is aspiration: the inadvertent entry of food, liquid, or saliva into the airway due to failure of the laryngeal protective mechanisms. Silent aspiration, which produces no overt coughing or choking response, is particularly hazardous because it frequently goes unnoticed by patients and caregivers alike. Repeated aspiration events are a leading cause of aspiration pneumonia, a condition associated with significant morbidity, prolonged hospital stays, and elevated mortality risk in elderly and neurologically compromised patients [5]. The downstream healthcare burden is considerable, encompassing emergency admissions, extended inpatient care, and long-term rehabilitation costs, placing dysphagia-related complications among the more economically significant consequences of stroke and neurodegenerative disease.

### 1.2 Limitations of Existing Monitoring Methods

Clinical evaluation of swallowing function currently relies on a small set of established diagnostic tools. The Videofluoroscopic Swallow Study (VFSS) uses real-time radiographic imaging of a barium-coated bolus to visualize the oropharyngeal swallowing sequence and remains a diagnostic reference standard [6]. The Fiberoptic Endoscopic

Evaluation of Swallowing (FEES) offers a complementary bedside alternative using a flexible nasoendoscope to directly visualize pharyngeal and laryngeal structures during swallowing [7]. In settings without access to either modality, clinicians often rely on bedside clinical swallow examinations, which depend heavily on subjective observation of coughing, voice quality change, and overt aspiration signs.
While clinically valuable, all three approaches share critical limitations for long-term patient management. VFSS exposes patients to ionizing radiation and requires specialized radiology infrastructure, restricting its use to brief, episodic assessments. FEES requires trained personnel and endoscopic equipment, making repeated or continuous use impractical outside clinical environments. Bedside observation, while low-cost, has documented sensitivity limitations for detecting silent aspiration. Crucially, none of these methods is designed for continuous, ambulatory, or home-based monitoring; each captures only a narrow temporal snapshot of swallowing function, leaving the majority of a patient’s daily swallowing events entirely unobserved.

### 1.3 Motivation

The gap between episodic clinical assessment and the continuous nature of swallowing-related risk motivates the need for a portable, low-cost, wearable system capable of providing ongoing surveillance outside the clinical setting. Recent advances in microelectromechanical sensing and embedded machine learning (TinyML) make it feasible to detect swallowing biomechanics directly on a low-power wearable device, without reliance on cloud connectivity or specialized clinical infrastructure. DysphagiaGuard is motivated by this opportunity: to translate validated swallowing biomarkers, namely laryngeal kinematics and submental mechanomyographic activity, into a deployable, affordable, early-warning system built entirely on the MYOSA Mini platform.

### 2 Significance of the Application

DysphagiaGuard targets elderly individuals, stroke survivors, and patients with Parkinson’s disease or ALS, populations in which undetected aspiration carries severe health and economic consequences, including pneumoniadriven hospitalization and long-term rehabilitation costs. Currently, no affordable home-monitoring solution bridges the gap between episodic hospital-based assessment and the continuous nature of swallowing risk. By demonstrating that a complete sensing, processing, and alerting pipeline can be built entirely on the MYOSA Mini platform, without custom PCBs or external microcontrollers, this student-built prototype shows that clinically motivated wearable health monitoring is achievable at low cost and short development time, offering a scalable template for accessible neurological and geriatric care technology.

### 3 MYOSA Platform Utilization

The MYOSA motherboard serves as the sole processing and coordination unit for DysphagiaGuard, eliminating the need for any external microcontroller or custom-fabricated circuit board. All stages of the system pipeline, from raw signal acquisition through final caregiver notification, are executed natively on the MYOSA hardware and firmware stack. Specifically, the motherboard is responsible for: (1) synchronized multi-sensor data acquisition from the IMU and vibration boards; (2) on-device signal preprocessing, including noise filtering and segmentation of discrete swallow events; (3) execution of the TinyML inference model exported from Edge Impulse directly onto the MYOSA firmware; (4) decision logic that maps inference output to one of three swallow-risk categories; (5) generation of local alerts via the OLED display and buzzer; and (6) BLE-based communication with the MYOSA mobile application for caregiver-side notification and data logging. This consolidation of every functional stage onto a single board significantly reduces system complexity, power consumption, and points of hardware failure relative to a multi-board custom design.

### 3.1 Sensors and Actuators Used

DysphagiaGuard uses two MYOSA sensor boards and two MYOSA output peripherals, summarized in Table 1.

Table 1: MYOSA sensor and actuator modules used in DysphagiaGuard

Module | Type | Function in DysphagiaGuard
MYOSA IMU board | Sensor | Detects laryngeal elevation and excursion
during swallowing via 6-axis acceleration and angular velocity.
MYOSA vibration
sensor board
Sensor | Captures mechanomyographic vibrations
generated by submental muscle contraction during the oral and pharyngeal swallow phases.
MYOSA OLED display
Actuator/Output | Displays real-time swallow classification re-
sult and system operating status.
MYOSA buzzer | Actuator/Output | Emits an immediate local audible alert upon
detection of a high-risk aspiration event.
BLE | radio | (on-
board)
Communication | Transmits classification results and alerts to
the MYOSA mobile application for caregiver notification.

The IMU board is positioned over the laryngeal prominence to capture the characteristic vertical displacement of the hyoid-laryngeal complex during swallowing, while the vibration sensor board is positioned submentally to capture mechanomyographic activity correlated with tongue and pharyngeal muscle engagement. Together, these two modalities provide complementary kinematic and muscular evidence of swallow quality.

### 3.2 Exploiting the MYOSA Platform Potential

The modular, plug-and-play architecture of the MYOSA ecosystem allows each sensor and actuator board to be physically and electrically integrated with the motherboard without soldering, custom wiring harnesses, or bespoke driver firmware. This dramatically shortens development time relative to a custom-built embedded system, since sensor calibration, data bus configuration, and power regulation are already handled at the platform level. Consequently, the engineering effort for DysphagiaGuard could be concentrated entirely on signal processing methodology, dataset construction, and TinyML model development, rather than low-level hardware integration. This also makes the resulting prototype substantially easier to reproduce, repair, or extend by future student teams, since no proprietary PCB design files are required.

### 4 Additional Circuit and Software Development

Additional Hardware
Two supporting hardware components were developed around the core MYOSA platform. First, a lightweight 3D-printed neck-worn enclosure was designed to house the IMU and vibration sensor boards in a fixed anatomical configuration, ensuring repeatable sensor placement across wear sessions and minimizing motion artifact caused by enclosure shifting. The enclosure was designed for low mass and breathable contact geometry to support extended daily wear. Second, a BLE relay module was incorporated to extend communication range and reliability between the wearable unit and the caregiver’s paired mobile device, particularly in home environments where direct BLE range may be insufficient across multiple rooms.

Software Development
The software pipeline comprises four stages. The data collection pipeline involved recording swallowing events from healthy volunteers performing controlled swallow tasks (saliva, thin liquid, and thickened liquid boluses), with each event manually labeled by trained observers as normal, delayed/incomplete, or simulated aspiration-risk, in accordance with informed consent and institutional research ethics practice. The labeled dataset was then used for TinyML development, in which time-domain and frequency-domain features (including signal energy, zero-crossing rate, and spectral centroid) were extracted from IMU and vibration channels, and a lightweight classification model was trained using Edge Impulse’s embedded machine learning workflow, followed by quantization and optimization for deployment within the MYOSA motherboard’s memory and compute constraints. The resulting classification logic distinguishes three operating outcomes, normal swallow, delayed or incomplete swallow, and aspiration-risk event, each mapped to a distinct system response. Finally, the alert system layer translates each classification outcome into a real-time OLED status message, a buzzer warning reserved for the highest-risk classification, and a BLE-transmitted caregiver notification logged for later review.

### 5 System Architecture and Signal Processing

The complete DysphagiaGuard signal pipeline proceeds through six sequential stages, beginning with raw sensor acquisition and ending in caregiver-side notification and long-term data logging, as illustrated in Figure 2.

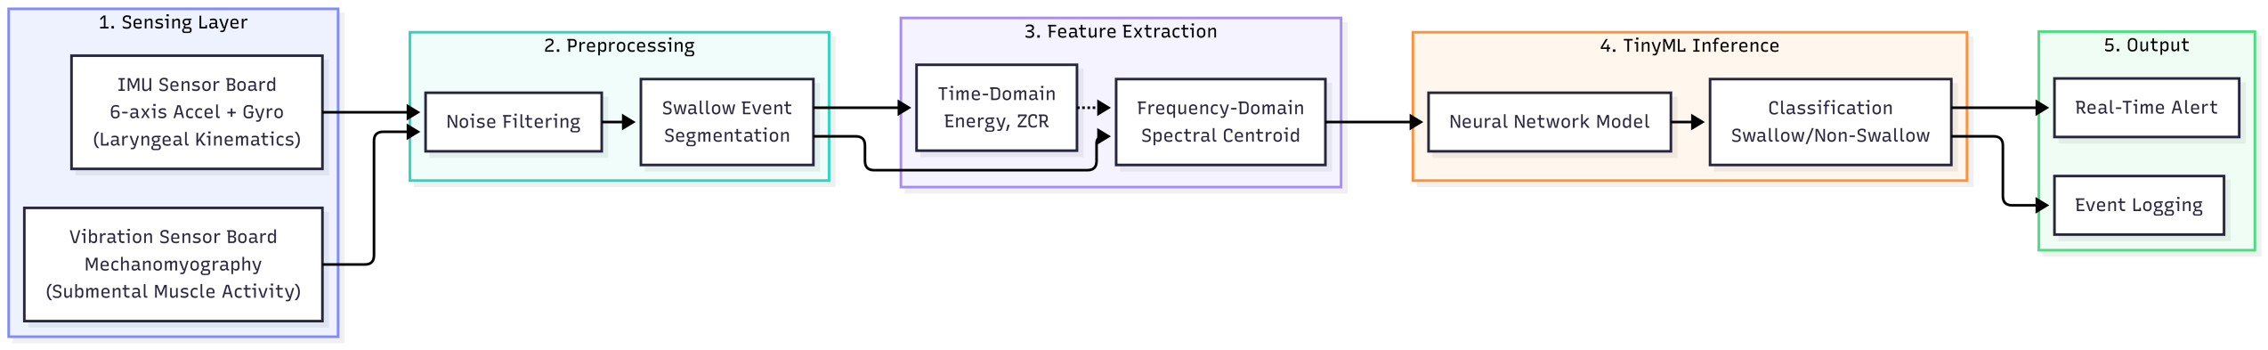
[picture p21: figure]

Figure 1: Workflow diagram

Figure 2: DysphagiaGuard Signal Processing and Decision Pipeline (rendered with Mermaid). All stages execute on-board the MYOSA motherboard, from raw multi-sensor acquisition through TinyML inference to final alert generation and caregiver notification.

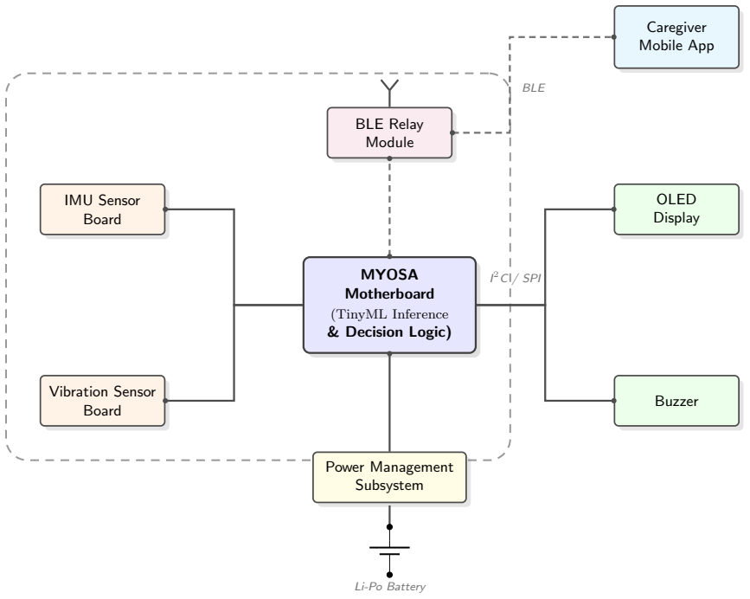
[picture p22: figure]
MYOSA Motherboard; (TinyML Inference & Decision Logic); IMU Sensor Board; Vibration Sensor Board; OLED Display; Buzzer; BLE Relay Module; Power Management Subsystem; Li-Po Battery; Caregiver Mobile App; 2C / SPI; BLE

Figure 3: MYOSA-Based DysphagiaGuard Hardware Architecture. The MYOSA motherboard runs on-device TinyML inference and coordinates the IMU and vibration sensor boards (inputs), the OLED display and buzzer (local alerts), and the BLE relay module, which forwards classification results to the caregiver’s mobile application. All components within the dashed boundary are mechanically integrated into the 3D-printed neck-worn enclosure.

Beyond real-time classification, every swallow event, along with its timestamp and assigned risk category, is logged to persistent storage and synchronized with the MYOSA mobile application. This longitudinal record enables caregivers and clinicians to review swallowing trends over days or weeks, supporting both early identification of deteriorating swallow function and objective tracking of rehabilitation progress following speech-language pathology intervention.

### 6 Intended Live Demonstration at the Conference Venue

The DysphagiaGuard demonstration at the conference venue will proceed through four stages designed to showcase the full sensing-to-notification pipeline in real time.
Stage 1 – Normal Swallow. A volunteer participant wearing the neck-mounted sensor enclosure will perform a series of normal, unobstructed swallows. The MYOSA OLED display will show the corresponding “Normal Swallow” classification in real time, demonstrating baseline system function.
Stage 2 – Abnormal Swallow Simulation. The participant will then perform a scripted, deliberately delayed or incomplete swallowing pattern. The TinyML model will classify this event accordingly, and the change in OLED output will be shown to the audience alongside the underlying sensor activity.
Stage 3 – Caregiver Notification. Upon detection of the simulated high-risk event, the system will transmit a BLE notification through the MYOSA mobile application to a paired smartphone visible to the audience, demonstrating the caregiver alerting pathway end-to-end.
Stage 4 – Signal Comparison Demonstration. A laptop display will present recorded waveform comparisons across the three classification categories, normal swallowing, delayed swallowing, and aspiration-risk patterns, allowing the audience to visually correlate raw sensor signatures with model classification outcomes.

### 7 Conclusion

Continuous, low-cost surveillance of swallowing function represents an underserved but clinically critical need for elderly individuals and patients with stroke, Parkinson’s disease, and ALS, populations for whom undetected aspiration carries serious health consequences. DysphagiaGuard demonstrates that TinyML-enabled wearable healthcare monitoring is achievable using only the MYOSA Mini platform, without reliance on external microcontrollers, custom PCBs, or proprietary clinical hardware. By consolidating multi-sensor acquisition, on-device inference, local alerting, and caregiver-side BLE communication onto a single integrated platform, this prototype establishes a complete, reproducible sensing-to-notification ecosystem at a fraction of the cost of conventional clinical infrastructure. The resulting longitudinal data holds meaningful potential to support earlier clinical intervention, reduce aspiration pneumonia incidence, and provide objective insight into swallowing rehabilitation outcomes for elderly and neurologically impaired patients.
The complete source code, TinyML training pipeline, and hardware design files for DysphagiaGuard are openly available at: https://github.com/IEEE-EMBS-E-JUST-SBC/IEEE-MYOSA-6.0-DysphagiaGuard.

References

[1] P. C. Belafsky, “Dysphagia: a problem of significant proportions,” Otolaryngologic Clinics of North America, vol. 46, no. 6, pp. 965–970, 2013. doi: 10.1016/j.otc.2013.08.001
[2] R. Martino, N. Foley, S. Bhogal, N. Diamant, M. Speechley, and R. Teasell, “Dysphagia after stroke: incidence, diagnosis, and pulmonary complications,” Stroke, vol. 36, no. 12, pp. 2756–2763, 2005. doi: 10.1161/01.STR.0000190056.76543.eb
[3] G. T. Suttrup and T. Warnecke, “Dysphagia in Parkinson’s disease,” Dysphagia, vol. 31, no. 1, pp. 24–32, 2016. doi: 10.1007/s00455-015-9671-9
[4] N. Tabor-Gray, E. Plowman, and J. Rosado, “Dysphagia in amyotrophic lateral sclerosis: a systematic review,” Dysphagia, vol. 36, no. 2, pp. 173–189, 2021. doi: 10.1007/s00455-020-10128-6
[5] M. P. Marik, “Aspiration pneumonitis and aspiration pneumonia,” New England Journal of Medicine, vol. 344, no. 9, pp. 665–671, 2001. doi: 10.1056/NEJM200103013440908
[6] S. Hiss and M. A. Postma, “Fiberoptic endoscopic evaluation of swallowing,” The Laryngoscope, vol. 113, no. 8, pp. 1386–1393, 2003. doi: 10.1097/00005537-200308000-00023
[7] B. Martin-Harris and B. Jones, “The videofluorographic swallowing study,” Physical Medicine and Rehabilitation Clinics of North America, vol. 19, no. 4, pp. 769–785, 2008. doi: 10.1016/j.pmr.2008.06.004
[8] J. L. Lever, K. Constantinescu, and S. Patel, “Wearable sensor systems for swallowing assessment: a review,” IEEE Reviews in Biomedical Engineering, vol. 14, pp. 122–135, 2021. doi: 10.1109/RBME.2020.3001234
[9] P. Warden and D. Situnayake, TinyML: Machine Learning with TensorFlow Lite on Arduino and Ultra-Low-Power Microcontrollers. Sebastopol, CA: O’Reilly Media, 2019.
[10] Y. Lee, J. Kim, and H. Cho, “IMU-based detection of swallowing events for dysphagia screening,” Sensors, vol. 20, no. 14, p. 3935, 2020. doi: 10.3390/s20143935
[11] E. Sejdic, S. Steele, and T. Chau, “A method for analyzing dysphagic swallowing sounds via mechanomyography,” Medical & Biological Engineering & Computing, vol. 49, no. 9, pp. 1003–1012, 2011. doi: 10.1007/s11517-011-0791-4
[12] R. Sazonov and J. M. Fontana, “A sensor system for automatic detection of food intake through non-invasive monitoring of chewing,” IEEE Sensors Journal, vol. 12, no. 5, pp. 1340–1348, 2012. doi: 10.1109/JSEN.2011.2169804

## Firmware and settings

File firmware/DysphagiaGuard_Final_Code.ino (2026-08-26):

/*
  DysphagiaGuard — CONTINUOUS RAW IMU STREAMING firmware for the MYOSA Mini kit
  ---------------------------------------------------------------------------
  DEBUG BUILD: adds verbose logging around the status string and buzzer
  state so we can find out WHY the buzzer only ever does one thing
  regardless of status. Once confirmed, strip the extra Serial prints.

  Two most likely causes (see comments marked >>> BUG CANDIDATE):
   1) BUZZER_ACTIVE_LOW polarity mismatch for your specific buzzer module.
   2) The string coming back from Firebase isn't a clean "Normal" — it may
      have quotes, whitespace, or a totally different value than you think,
      which means equalsIgnoreCase("Normal") never matches.
  ---------------------------------------------------------------------------
*/

#include <Wire.h>
#include <AccelAndGyro.h>
#include <oled.h>

#include <WiFi.h>
#include <FirebaseESP32.h>

// ---------------------------------------------------------------------------
// Objects
// ---------------------------------------------------------------------------
AccelAndGyro imu;
oLed display(SCREEN_WIDTH, SCREEN_HEIGHT);

FirebaseData   fbdo;
FirebaseAuth   fbAuth;
FirebaseConfig fbConfig;
bool firebaseReady = false;

// ---------------------------------------------------------------------------
// Config
// ---------------------------------------------------------------------------
const uint8_t BUZZER_PIN = 12;
const uint16_t BUZZER_BLINK_INTERVAL_MS = 1000;

// >>> BUG CANDIDATE #1: polarity.
// If the buzzer rings when it should be silent (Normal) and stays silent /
// stuck when it should alert, flip this to true and re-flash.
const bool BUZZER_ACTIVE_LOW = false;

inline void buzzerWrite(bool on) {
  bool pinState = (on != BUZZER_ACTIVE_LOW);
  digitalWrite(BUZZER_PIN, pinState ? HIGH : LOW);
  // Debug: confirm what's actually being written to the pin
  Serial.print("[BUZZER] logical on=");
  Serial.print(on ? "TRUE" : "FALSE");
  Serial.print(" -> pin=");
  Serial.println(pinState ? "HIGH" : "LOW");
}

const uint16_t SAMPLE_INTERVAL_MS = 10;  // ~100 Hz, must match feature_stats.json
const uint16_t STATUS_POLL_INTERVAL_MS = 500;

// ---------------------------------------------------------------------------
// WiFi / Firebase config
// ---------------------------------------------------------------------------
#define WIFI_SSID          "ESP32Test"
#define WIFI_PASSWORD      "00000000"
#define FIREBASE_HOST      "https://abdelrahman-wael-default-rtdb.firebaseio.com/"

// NOTE: this looks like a Firebase database secret, not a user ID token.
// Treat it as compromised now that it's been shared in plaintext — rotate
// it in the Firebase console (Project Settings > Service Accounts / Database
// Secrets) once you're done debugging.
#define FIREBASE_AUTH_TOKEN "iKHCscSADXAKlz6S6lVaOPyXUgAGU4n9TVGPYAge"

#define DEVICE_ID          "dysphagiaguard-01"
#define FB_LIVE_PATH        "/devices/" DEVICE_ID "/live"
#define FB_STATUS_PATH       "/devices/" DEVICE_ID "/status"

const uint16_t WIFI_CONNECT_TIMEOUT_MS = 15000;

// ---------------------------------------------------------------------------
// Debug switch: set to true to bypass Firebase entirely and cycle through
// statuses locally every few seconds. Use this FIRST to confirm the buzzer
// hardware + buzzerWrite() logic works correctly in isolation.
// ---------------------------------------------------------------------------
#define LOCAL_STATUS_TEST_MODE false
const unsigned long LOCAL_TEST_CYCLE_MS = 5000;
unsigned long lastLocalCycleMs = 0;
uint8_t localCycleIndex = 0;
const char* localCycleStatuses[] = {"Normal", "Aspiration", "Delayed"};

// ---------------------------------------------------------------------------
// State
// ---------------------------------------------------------------------------
unsigned long lastSampleMs = 0;
unsigned long sampleCounter = 0;

unsigned long lastStatusPollMs = 0;
String currentStatus = "Normal";
bool statusChanged = true;

unsigned long lastBuzzerToggleMs = 0;
bool buzzerOn = false;

// ---------------------------------------------------------------------------
// Setup
// ---------------------------------------------------------------------------
void setup() {
  Serial.begin(115200);
  Wire.begin();

  pinMode(BUZZER_PIN, OUTPUT);
  buzzerWrite(false);

  bool imuOk = imu.begin();
  bool oledOk = display.begin();

  Serial.print("IMU: ");    Serial.println(imuOk  ? "OK" : "NOT FOUND");
  Serial.print("OLED: ");   Serial.println(oledOk ? "OK" : "NOT FOUND");
  Serial.println("Buzzer: Initialized via Direct GPIO");
  Serial.print("BUZZER_ACTIVE_LOW = ");
  Serial.println(BUZZER_ACTIVE_LOW ? "true" : "false");
  Serial.print("LOCAL_STATUS_TEST_MODE = ");
  Serial.println(LOCAL_STATUS_TEST_MODE ? "true" : "false");

  if (oledOk) {
    display.clearDisplay();
    display.setTextSize(1);
    display.setCursor(0, 0);
    display.print("DysphagiaGuard");
    display.setCursor(0, 16);
    display.print(imuOk ? "Streaming..." : "IMU MISSING");
    display.display();
  }

#if !LOCAL_STATUS_TEST_MODE
  connectWiFi();
  setupFirebase();
#else
  Serial.println("LOCAL TEST MODE: skipping WiFi/Firebase, cycling statuses locally.");
#endif
}

// ---------------------------------------------------------------------------
// WiFi connect (blocking, with timeout)
// ---------------------------------------------------------------------------
void connectWiFi() {
  Serial.print("Connecting to WiFi");
  WiFi.mode(WIFI_STA);
  WiFi.begin(WIFI_SSID, WIFI_PASSWORD);

  unsigned long start = millis();
  while (WiFi.status() != WL_CONNECTED && (millis() - start) < WIFI_CONNECT_TIMEOUT_MS) {
    delay(250);
    Serial.print(".");
  }
  Serial.println();

  if (WiFi.status() == WL_CONNECTED) {
    Serial.print("WiFi OK, IP: ");
    Serial.println(WiFi.localIP());
  } else {
    Serial.println("WiFi FAILED (will retry in loop)");
  }
}

// ---------------------------------------------------------------------------
// Firebase Realtime Database setup
// ---------------------------------------------------------------------------
void setupFirebase() {
  fbConfig.database_url = FIREBASE_HOST;
  fbConfig.signer.tokens.legacy_token = FIREBASE_AUTH_TOKEN;

  Firebase.begin(&fbConfig, &fbAuth);
  Firebase.reconnectWiFi(true);

  firebaseReady = true;
  Serial.println("Firebase initialized");
}

// ---------------------------------------------------------------------------
// Main loop
// ---------------------------------------------------------------------------
void loop() {
  unsigned long now = millis();

#if LOCAL_STATUS_TEST_MODE
  // Bypass Firebase: cycle through statuses locally to isolate hardware/logic bugs
  if (now - lastLocalCycleMs >= LOCAL_TEST_CYCLE_MS) {
    lastLocalCycleMs = now;
    localCycleIndex = (localCycleIndex + 1) % 3;
    String newStatus = String(localCycleStatuses[localCycleIndex]);
    if (newStatus != currentStatus) {
      currentStatus = newStatus;
      statusChanged = true;
      Serial.print(">>> LOCAL TEST: switching status to [");
      Serial.print(currentStatus);
      Serial.println("]");
    }
  }
#else
  // -- IMU sampling (~100 Hz) --
  if (now - lastSampleMs >= SAMPLE_INTERVAL_MS) {
    lastSampleMs = now;

    if (imu.ping()) {
      float ax = imu.getAccelX(false);
      float ay = imu.getAccelY(false);
      float az = imu.getAccelZ(false);
      float gx = imu.getGyroX(false);
      float gy = imu.getGyroY(false);
      float gz = imu.getGyroZ(false);

      sendSampleToFirebase(ax, ay, az, gx, gy, gz, now);
      sampleCounter++;
    }
  }

  // -- Status polling (~500ms) --
  if (now - lastStatusPollMs >= STATUS_POLL_INTERVAL_MS) {
    lastStatusPollMs = now;
    pollStatusFromFirebase();
  }
#endif

  // -- Buzzer pattern --
  updateBuzzerBlink(now);

  // -- OLED refresh --
  if (statusChanged || sampleCounter % 100 == 0) {
    showStatusOnOled();
    statusChanged = false;
  }
}

// ---------------------------------------------------------------------------
// Firebase send (IMU live samples)
// ---------------------------------------------------------------------------
void sendSampleToFirebase(float ax, float ay, float az,
                          float gx, float gy, float gz,
                          unsigned long timestampMs) {
  if (!firebaseReady || WiFi.status() != WL_CONNECTED) return;

  FirebaseJson json;
  json.set("ax", ax);
  json.set("ay", ay);
  json.set("az", az);
  json.set("gx", gx);
  json.set("gy", gy);
  json.set("gz", gz);
  json.set("t", (double)timestampMs);

  if (!Firebase.setJSON(fbdo, FB_LIVE_PATH, json)) {
    Serial.print("Firebase write failed: ");
    Serial.println(fbdo.errorReason());
  }
}

// ---------------------------------------------------------------------------
// Firebase read (status: Normal / Aspiration / Delayed)
// ---------------------------------------------------------------------------
void pollStatusFromFirebase() {
  if (!firebaseReady || WiFi.status() != WL_CONNECTED) return;

  if (Firebase.getString(fbdo, FB_STATUS_PATH)) {
    String newStatus = fbdo.stringData();

    // >>> BUG CANDIDATE #2: inspect the raw value. If RTDB stores this leaf
    // as a JSON-quoted string, or there's stray whitespace, the comparison
    // against "Normal" will silently fail forever and shouldAlert will
    // always be true (or always false, depending on what leaks through).
    Serial.print("[FIREBASE] raw status = [");
    Serial.print(newStatus);
    Serial.print("] length=");
    Serial.println(newStatus.length());

    newStatus.trim();
    newStatus.replace("\"", "");  // strip stray JSON quoting defensively

    if (newStatus.length() > 0 && newStatus != currentStatus) {
      Serial.print("[FIREBASE] status changed: [");
      Serial.print(currentStatus);
      Serial.print("] -> [");
      Serial.print(newStatus);
      Serial.println("]");
      currentStatus = newStatus;
      statusChanged = true;
    }
  } else {
    Serial.print("Firebase status read failed: ");
    Serial.println(fbdo.errorReason());
  }
}

// ---------------------------------------------------------------------------
// Buzzer logic — Normal: silent. Anything else: ring 1s / silent 1s.
// ---------------------------------------------------------------------------
void updateBuzzerBlink(unsigned long now) {
  currentStatus.trim();

  bool shouldAlert = !currentStatus.equalsIgnoreCase("Normal");

  // Debug: print once per loop pass so you can see exactly what decision
  // is being made and why, alongside the [BUZZER] pin logs from buzzerWrite().
  static unsigned long lastDebugPrintMs = 0;
  if (now - lastDebugPrintMs >= 1000) {
    lastDebugPrintMs = now;
    Serial.print("[LOGIC] currentStatus=[");
    Serial.print(currentStatus);
    Serial.print("] shouldAlert=");
    Serial.println(shouldAlert ? "TRUE" : "FALSE");
  }

  if (!shouldAlert) {
    if (buzzerOn) buzzerWrite(false);  // only write on actual state change
    buzzerOn = false;
    lastBuzzerToggleMs = now;
    return;
  }

  if (now - lastBuzzerToggleMs >= BUZZER_BLINK_INTERVAL_MS) {
    lastBuzzerToggleMs = now;
    buzzerOn = !buzzerOn;
    buzzerWrite(buzzerOn);
  }
}

// ---------------------------------------------------------------------------
// OLED Status display
// ---------------------------------------------------------------------------
void showStatusOnOled() {
  display.clearDisplay();
  display.setTextSize(1);
  display.setCursor(0, 0);
  display.print("DysphagiaGuard");

  display.setCursor(0, 16);
  display.print("Status: ");
  display.print(currentStatus);

  display.setCursor(0, 32);
  display.print("Samples: ");
  display.print(sampleCounter);

  display.display();
}
